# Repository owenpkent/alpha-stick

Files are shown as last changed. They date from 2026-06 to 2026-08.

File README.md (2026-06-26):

<div align="center">
  <h1>🎮 Alpha Stick</h1>
  <p><strong>Open-Source Adaptive Gaming Joystick</strong></p>
  <p>
    A 3D-printable, ESP32-powered joystick designed for gamers with limited mobility.<br/>
    Inspired by commercial solutions like QuadStick and Feather — but fully open and hackable.
  </p>
  <p>
    
    
    
    
    
    
  </p>
  <p>
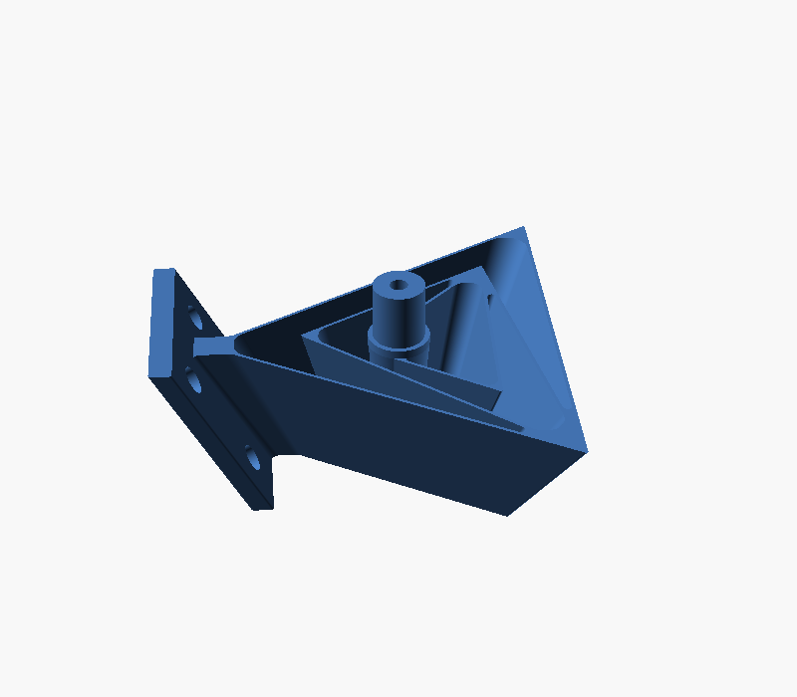
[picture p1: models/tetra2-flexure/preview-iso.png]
Tetra II spherical flexure joint — the primary pivot mechanism
    
  </p>
  <p><em>The pivot is a <strong>Tetra II spherical flexure</strong>: bearing-free, frictionless, and self-centering — the first gram of input already moves it.</em></p>
  <p>
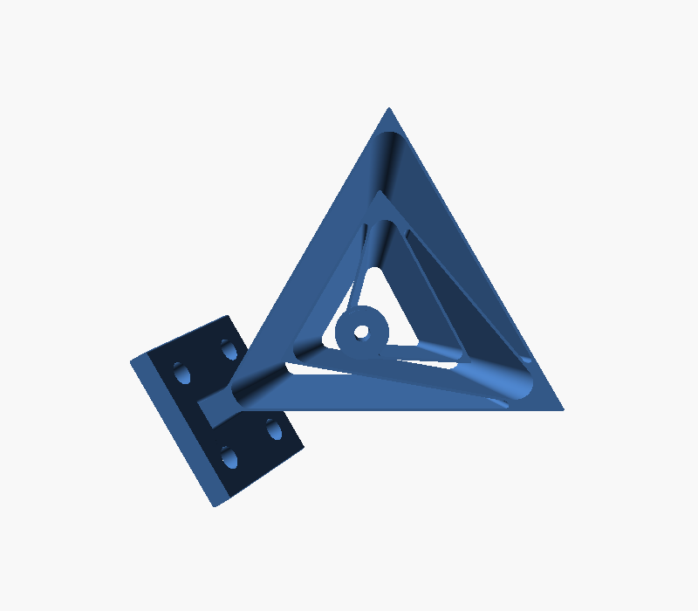
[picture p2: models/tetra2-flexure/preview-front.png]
Tetra II flexure — front view
    
    &nbsp;
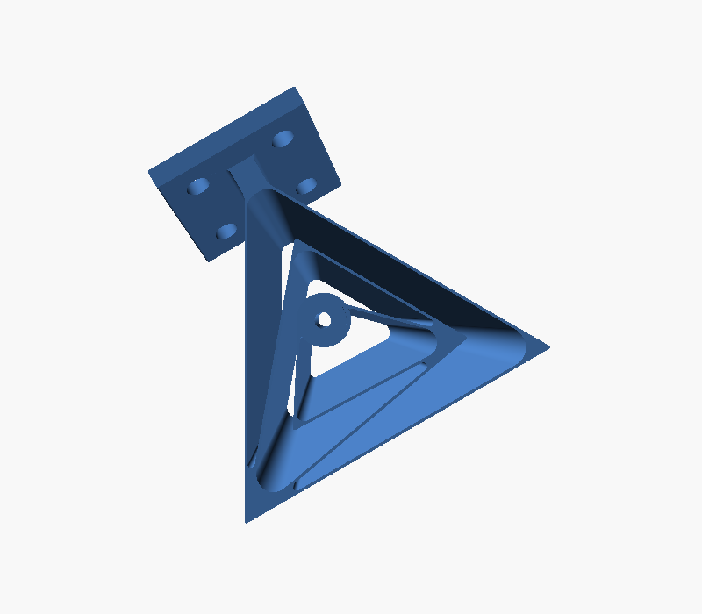
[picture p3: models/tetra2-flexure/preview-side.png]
Tetra II flexure — side view
    
  </p>
</div>

---

**New here?** Read the [Executive Summary](docs/EXECUTIVE_SUMMARY.md) (one page) or the [Whitepaper](docs/WHITEPAPER.md) (the full technical story). Want to help? See [CONTRIBUTING.md](CONTRIBUTING.md).

## Status

**Phase 0: Bench Validation** — V2 design baseline complete; proving the physics (force, noise, latency) before any product claims.

| Area | Status |
|---|---|
| Pivot mechanism | ✅ **Tetra II spherical flexure (primary)** — CAD in [`models/tetra2-flexure/`](models/tetra2-flexure/); ball-in-PTFE pod kept as the alternative |
| V2 First-Principles Design | 🔄 Baseline written: [docs/DESIGN_V2.md](docs/DESIGN_V2.md) |
| Hardware Design | ⏳ Planning (flexure pod + main board) |
| 3D Print Files | 🔄 Flexure STEP/STL in repo; pod bodies in progress |
| Firmware | ⏳ Planning |
| Documentation | 🔄 In Progress |
| Project Nimbus Integration | ⏳ Planned |

---

## Why Alpha Stick?

Commercial adaptive controllers are **expensive** ($200–$500+) and often **proprietary**. Gamers with disabilities deserve affordable, customizable options they can build, modify, and repair themselves.

**Alpha Stick aims to provide:**

- **Affordable** — 3D-printed enclosure + off-the-shelf electronics (~$30–50 BOM)
- **Open Source** — Hardware, firmware, and documentation all freely available
- **Customizable** — Modular design adaptable to different needs and abilities
- **Updateable** — OTA firmware updates via ESP32
- **Compatible** — Works with Xbox Adaptive Controller, PlayStation Access Controller, PC, and [Project Nimbus](https://github.com/owenpkent/Project-Nimbus)

---

## Inspiration

Alpha Stick draws from the best features of existing adaptive controllers:

| Product | Key Features We're Inspired By |
|---|---|
| **[QuadStick](https://www.quadstick.com/)** | Mouth-operated joystick, sip/puff input, multi-platform support |
| **[Feather](https://www.celticmagic.org/feather)** | Ultra-light force (<5g), magnetic sensing, tremor filter, adjustable sensitivity |
| **[Xbox Adaptive Controller](https://www.xbox.com/en-US/accessories/controllers/xbox-adaptive-controller)** | 3.5mm jack inputs, USB hub, profile switching, 3D-printable accessories |
| **[PlayStation Access](https://www.playstation.com/en-us/accessories/access-controller/)** | Swappable button caps, adjustable stick length, expandable inputs |
| **[Titan Two](https://www.consoletuner.com/products/titan-two/)** | Cross-platform compatibility, scripting, keyboard/mouse support |

---

## Planned Features

### Hardware
- **ESP32-S3** microcontroller with Bluetooth LE and USB HID
- **Tetra II spherical flexure pivot** — bearing-free, frictionless, self-centering; no springs, no break-away force
- **Contactless dual-Hall sensing** — a tilting magnet read by two TMAG5273 sensors; immune to temperature and creep
- **Ultra-low force** — under 5 grams full deflection, set by the flexure's blade geometry
- **3.5mm input jacks** — connect external switches and buttons
- **Modular enclosure** — 3D-printed, designed for different mounting options
- **Sip/puff interface** (optional) — pressure sensor input

### Firmware
- **USB HID gamepad** — plug-and-play on PC/consoles
- **Bluetooth LE gamepad** — wireless connection
- **XInput/DirectInput modes** — broad game compatibility
- **OTA updates** — update firmware over WiFi
- **Web-based configuration** — adjust sensitivity, deadzone, button mapping via browser
- **Profile system** — save and switch between configurations
- **Tremor filter** — configurable smoothing for users with tremors

### Software Integration
- **Project Nimbus integration** — use Alpha Stick with the virtual controller interface
- **Xbox Adaptive Controller companion** — connect via 3.5mm or USB
- **Configuration app** — desktop/mobile app for settings (future)

---

## Target Platforms

- **PC** — Windows (USB/Bluetooth), Linux, macOS
- **Xbox** — Via Xbox Adaptive Controller (3.5mm jack or USB)
- **PlayStation** — Via PS Access Controller or adapter
- **Nintendo Switch** — Via USB or Bluetooth (with appropriate mode)
- **Mobile** — Android/iOS via Bluetooth

---

## Project Structure

```
alpha-stick/
├── README.md                 # This file
├── LICENSE                   # MIT License
├── TODO.md                   # Task tracking
├── LLM_ONBOARDING.md         # AI assistant reference
├── docs/
│   ├── EXECUTIVE_SUMMARY.md  # One page: what and why
│   ├── WHITEPAPER.md         # The full technical narrative
│   ├── DESIGN_V2.md          # V2 design baseline (working doc)
│   ├── WORKFLOW.md           # Development loops & conventions
│   ├── HARDWARE.md           # Build reference & BOM
│   ├── FIRMWARE.md           # Firmware architecture (ESP-IDF)
│   ├── PHASE0_PARTS.md       # Bench parts list
│   ├── BENCH_LOG.md          # Measured results
│   ├── PRINTING.md           # 3D printing guide
│   ├── ASSEMBLY.md           # Assembly instructions
│   └── CONFIGURATION.md      # Configuration guide
├── hardware/
│   ├── schematics/           # KiCad or EasyEDA files
│   ├── pcb/                  # PCB design files
│   └── bom/                  # Bill of materials
├── firmware/
│   ├── main/                 # Entry point, mode supervisor
│   ├── components/           # Sensing, pipeline, HID, AS-Link, config
│   ├── web/                  # Web config UI source
│   └── sdkconfig.defaults    # ESP-IDF configuration
├── models/
│   ├── tetra2-flexure/       # Primary pivot: Tetra II flexure STEP + STL (CC-BY)
│   ├── stl/                  # Ready-to-print STL files (alternative pod)
│   ├── step/                 # STEP files for modification
│   └── source/               # FreeCAD/Fusion360 source files
├── software/
│   ├── web-config/           # Web-based configuration UI
│   └── tools/                # Utility scripts
└── examples/
    └── profiles/             # Example configuration profiles
```

---

## Hardware Overview

### Core Components

| Component | Purpose | Est. Cost |
|---|---|---|
| ESP32-S3 module | Main controller | $4–10 |
| Sensor pod (Tetra II flexure pivot + dual Hall + magnet) | Position input, <5 g force, self-centering | $5–7 |
| 3.5mm jacks (x4) | External switch inputs | $2 |
| Buttons (x2–4) | Direct button inputs | $1–2 |
| 3D-printed enclosure | Housing | $2–5 (filament) |
| USB-C connector | Power/data | $1 |
| Misc (wires, screws) | Assembly | $2–3 |
| **Total** | | **~$20–30** |

### Optional Add-ons

| Component | Purpose | Est. Cost |
|---|---|---|
| Hall-effect joystick | Ultra-smooth input | $10–20 |
| Pressure sensor | Sip/puff interface | $5–10 |
| LiPo battery + charger | Wireless operation | $10–15 |
| OLED display | Status/config display | $5 |

---

## Getting Started

> **Note:** Hardware and firmware are still in development. Check back soon!

### Prerequisites

- **3D Printer** — Any FDM printer (Ender 3, Prusa, etc.)
- **Soldering iron** — Basic through-hole soldering
- **ESP-IDF 5.x** — For firmware development ([install](https://docs.espressif.com/projects/esp-idf/en/stable/esp32s3/get-started/index.html))
- **ESP32-S3 board** — DevKitC or similar

### Quick Start (Coming Soon)

```powershell
# Clone the repository
git clone https://github.com/owenpkent/alpha-stick.git

# Navigate to firmware directory
cd alpha-stick/firmware

# Build and flash (ESP-IDF PowerShell)
idf.py set-target esp32s3; idf.py build flash

# Open web configuration
# Connect to "AlphaStick" WiFi network, navigate to http://192.168.4.1
```

---

## Project Nimbus Integration

Alpha Stick is designed to work seamlessly with [**Project Nimbus**](https://github.com/owenpkent/Project-Nimbus) — a virtual controller interface for accessibility.

### Integration Options

1. **Direct USB** — Alpha Stick appears as a standard gamepad; Project Nimbus can combine it with mouse input
2. **Bluetooth** — Wireless connection to PC running Project Nimbus
3. **Hybrid mode** — Use Alpha Stick for analog input, Project Nimbus for buttons and additional controls
4. **Configuration sync** — Share sensitivity curves and profiles between projects

### Use Cases

- **Alpha Stick + Project Nimbus** — Physical joystick for one hand, on-screen buttons for the other
- **Dual Alpha Sticks** — Two joysticks for flight sim or dual-stick shooters
- **Alpha Stick + Xbox Adaptive Controller** — Use Alpha Stick as an external joystick input

---

## Accessibility Features

Designed with input from the disability gaming community:

- **Ultra-light force** — under 5 g full deflection from the flexure; swap to a stiffer-blade flexure (or the adjustable ball-pivot pod) to retune
- **Configurable deadzone** — Accommodate tremors and limited precision
- **Tremor filtering** — Smooth out unintended movements
- **Button debouncing** — Adjustable for different switch types
- **One-handed operation** — Compact form factor, all controls accessible
- **Voice/switch control** — External switch inputs for additional buttons
- **Custom mounting** — Designed for RAM mounts, Magic Arms, and wheelchair trays

---

## Contributing

We welcome contributions from everyone! Areas where we especially need help:

- **3D modeling** — Enclosure designs for different needs
- **PCB design** — If you have KiCad/EasyEDA experience
- **Firmware development** — ESP32, ESP-IDF, Bluetooth HID
- **Testing** — Especially from users with disabilities
- **Documentation** — Tutorials, translations, videos

### How to Contribute

1. Fork the repository
2. Create a feature branch (`git checkout -b feature/my-feature`)
3. Make your changes with clear commit messages
4. Submit a pull request

See [CONTRIBUTING.md](CONTRIBUTING.md) for detailed guidelines.

---

## Roadmap

### Phase 1: Foundation (Current)
- [ ] Define hardware requirements
- [ ] Select core components
- [ ] Create initial 3D model
- [ ] Basic firmware scaffold

### Phase 2: Prototype
- [ ] Working breadboard prototype
- [ ] USB HID functionality
- [ ] Basic web configuration
- [ ] First printable enclosure

### Phase 3: Refinement
- [ ] Bluetooth support
- [ ] OTA updates
- [ ] Sip/puff option
- [ ] Community testing

### Phase 4: Release
- [ ] Documentation complete
- [ ] Multiple enclosure options
- [ ] Profile library
- [ ] v1.0 release

---

## Community

- **GitHub Issues** — Bug reports, feature requests, questions
- **Discussions** — Share your builds, ask for help
- **Discord** — (Coming soon)

---

## Related Projects

- **[Project Nimbus](https://github.com/owenpkent/Project-Nimbus)** — Virtual controller interface for accessibility
- **ATOS** — Modular ESP32-S3 wheelchair platform; Alpha Stick V2 is designed to act as its input node (see [docs/DESIGN_V2.md](docs/DESIGN_V2.md), section 9)
- **[Joypad OS](https://github.com/joypad-ai/joypad-os)** — Universal controller firmware for adapters and protocol translation (reference architecture)
- **[Xbox Adaptive Controller](https://www.xbox.com/en-US/accessories/controllers/xbox-adaptive-controller)** — Microsoft's adaptive gaming hub
- **[QuadStick](https://www.quadstick.com/)** — Commercial mouth-operated controller
- **[Feather Joystick](https://www.celticmagic.org/feather)** — Ultra-light force joystick
- **[OpenSwitchBoard](https://github.com/makersmakingchange/OpenSwitchBoard)** — Open-source switch interface
- **[Makers Making Change](https://makersmakingchange.com/)** — Community building assistive technology

---

## License

- **Code & firmware** — [MIT License](LICENSE).
- **Original hardware designs** (the pod, bench rig, bodies, toppers) — **CERN-OHL-P v2** (permissive), see [LICENSE-CERN-OHL-P-2.0.txt](LICENSE-CERN-OHL-P-2.0.txt).
- **Tetra II spherical flexure** (the primary pivot) — third-party design by Jelle Rommers under **Creative Commons Attribution (CC BY 3.0)**, used unmodified; credit is required if you share or build on it. See [models/tetra2-flexure/LICENSE](models/tetra2-flexure/LICENSE).

Bundled third-party components and their attribution are listed in [NOTICE.md](NOTICE.md).

---

## Acknowledgments

- The disability gaming community for feedback and inspiration
- [AbleGamers](https://ablegamers.org/) and [SpecialEffect](https://www.specialeffect.org.uk/) for advocacy
- Owen — project creator, wheelchair user with muscular dystrophy
- Everyone building accessible gaming solutions

---

<div align="center">
  <strong>Gaming is for everyone. Let's build it together.</strong>
</div>

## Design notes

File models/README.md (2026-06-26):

# Models

Printable parts for Alpha Stick V2. Print settings live in
[docs/PRINTING.md](../docs/PRINTING.md); the design rationale in
[docs/DESIGN_V2.md](../docs/DESIGN_V2.md).

## Tetra II flexure: the primary pivot mechanism

Alpha Stick V2 pivots on the **Tetra II spherical flexure joint** in
[`tetra2-flexure/`](tetra2-flexure/). It is a bearing-free compliant gimbal:
nested tetrahedron blade flexures give 3-DOF rotation about a remote centre that
floats ~50 mm out from the joint, with **no sliding surfaces** — so no friction,
no backlash, no break-away force, and the blades themselves provide the elastic
return to centre (no centering magnet, no spring, no threaded force adjuster).
The diametric sense magnet rides the moving platform and the dual TMAG5273 Hall
sensors read tilt exactly as before; only the pivot-and-return mechanism changes.

Tetra II flexure — isometric
Tetra II flexure — front
Tetra II flexure — side

| File | What it is |
|---|---|
| [`tetra2-flexure/Tetra2.STEP`](tetra2-flexure/Tetra2.STEP) | source CAD (B-rep); scale, thicken blades, or cut a stick mount in FreeCAD / Fusion / SolidWorks |
| [`tetra2-flexure/Tetra2.STL`](tetra2-flexure/Tetra2.STL) | ready-to-slice mesh of the same part |
| [`tetra2-flexure/README.md`](tetra2-flexure/README.md) | paper analysis, printing notes, and CC-BY attribution |

This is Jelle Rommers' design and carries an upstream **CC-BY** licence (credit
required), separate from the repo's MIT / CERN-OHL-P work — see the folder
README. Stiffness (= the force you feel) is hard to predict for the real
tetrahedron element and is set by blade geometry, material, and scale, so it is
a **Phase 0 bench measurement**, not a hand-calculated figure. A printed PLA
joint is fine for feel studies but creeps and fatigues under daily use; PETG or
a printed-then-cast/metal version are the follow-ups.

## Pod v0: the ball-pivot bench rig (alternative mechanism)

The pod parts below build the **alternative** ball-in-PTFE-cup mechanism with
magnetic centering — the original V2 path, kept as a fallback and as the bench
rig that characterises the dual-Hall sensing independent of the pivot choice
(see [docs/HARDWARE.md](../docs/HARDWARE.md#alternative-mechanism-ball-in-ptfe-pod)).

`source/pod-v0.scad` (OpenSCAD, fully parametric) generates the rig that
validates the V2 mechanism using the parts from
[docs/PHASE0_PARTS.md](../docs/PHASE0_PARTS.md). It is sized around the
**SparkFun Qwiic TMAG5273 breakout** (25.4 mm square), not the final 20 x 20 mm
pod PCB; v0 exists to produce the numbers the real pod gets sized from.

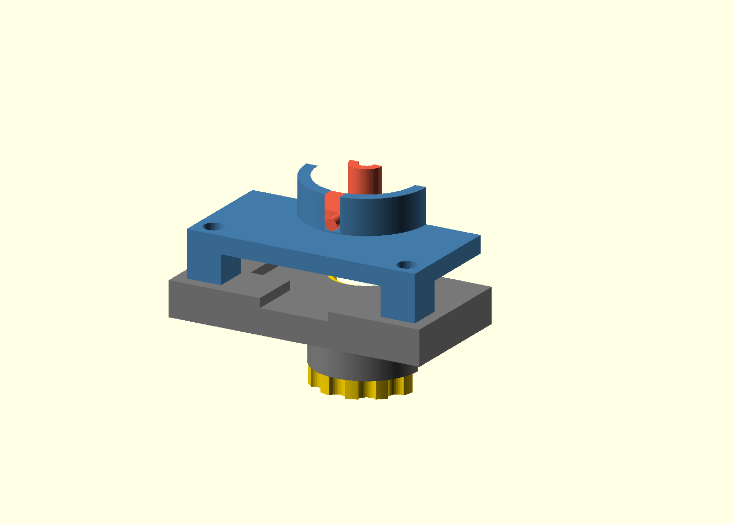
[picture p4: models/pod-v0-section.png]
Assembly cross-section


| Part | STL | What it does |
|---|-----|---|
| Stick hub | `stl/pod/stick-hub-v0.stl` | Printed dome pivot, D4x2 diametric magnet pocket (0.2 mm proud), anti-yaw pins, 2.6 mm carbon tube bore |
| Seat housing | `stl/pod/seat-housing-v0.stl` | PTFE-tape-lined spherical socket on a bridge over the breakout, anti-yaw slots, corner posts |
| Bench base | `stl/pod/bench-base-v0.stl` | Breakout pocket (PCB top lands flush), M12x0.75 threaded boss for the carrier, Qwiic cable reliefs |
| Adjuster carrier | `stl/pod/adjuster-carrier-v0.stl` | M12x0.75 thread, top pocket for a D10 ring magnet or M5 washer stack, grip wheel |
| Ball topper | `stl/toppers/topper-ball-v0.stl` | 8 mm ball, press-fits the carbon tube |
| Thread guide | `stl/pod/thread-guide-v0.stl` | String guide arm for the gram-scale force rig, notch near the 40 mm grip height |

### How the mechanism works in v0

The hub's printed dome (R6) rests in the housing socket lined with PTFE tape.
The sense magnet in the dome flat sits 1.5 mm above the TMAG5273 (the stack
arithmetic is derived, commented, and echoed in the .scad). The carrier rises
through the base from below; whatever sits in its pocket (ring magnet, washer
stack, or steel disc) attracts the sense magnet downward: that one attraction
is simultaneously the pivot preload and the centering force. Screwing the
carrier up or down sweeps the magnet-to-armature gap from about 4.4 to 9 mm,
which is the 1-8 gf force adjustment under test. Anti-yaw pins in collar slots
stop the hub from spinning (a diametric magnet reads yaw as direction change,
so this is required, not cosmetic). Tilt limit with default numbers: ~7 deg.

### v0 deviations from the production pod (docs/HARDWARE.md)

- Printed dome instead of a discrete steel ball; the bench compares feel and
  breakout force, and the steel-ball variant returns if PTFE-on-PETG loses.
- No steel washer on the hub; centering acts directly on the sense magnet.
- No carrier detents; printed-thread friction holds position at gram loads.
- ASSEMBLY.md describes the production pod build; for v0, assembly is: glue
  magnet in hub, tape the socket, drop hub in housing, screw housing to base
  over the breakout, thread the carrier in from below.

### Print notes

- Hub and housing at 0.12 mm; both export pre-flipped to their print
  orientation (hub neck-down so the dome prints as a smooth top surface;
  housing collar-down so the socket bowl faces up). No supports.
- The hub's anti-yaw pins print as short horizontal cantilevers; a little sag
  is fine (the slots have 0.6 mm total clearance).
- Base prints boss-down as exported, brim recommended.
- Thread binds? Adjust `thr_clr` (default 0.18) and reprint just the carrier.

### Regenerating

Edit parameters at the top of `source/pod-v0.scad`, then:

```powershell
& "C:\Program Files\OpenSCAD\openscad.com" -o models\stl\pod\stick-hub-v0.stl -D "part=`"hub`"" models\source\pod-v0.scad
```

Part selector values: `hub`, `housing`, `base`, `carrier`, `topper`, `guide`,
`plate` (all parts in print orientation), `section` (assembly cross-section).

## Layout

```
models/
+-- tetra2-flexure/  primary pivot: Tetra II flexure STEP + STL (third-party, CC-BY)
+-- source/          pod-v0.scad (parametric source of truth for the alternative pod)
+-- stl/             ready-to-print pod exports (regenerate after editing source)
+-- step/            reserved for the production pod (FreeCAD/Fusion era)
+-- community/       community-contributed toppers and bodies (created on first PR)
```

Third-party parts (currently the Tetra II flexure) keep their upstream licence
in their own folder README; everything else is the repo's MIT / CERN-OHL-P work.

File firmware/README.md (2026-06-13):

# Alpha Stick Firmware

ESP-IDF 5.x scaffold implementing the architecture in [docs/FIRMWARE.md](../docs/FIRMWARE.md).

> **Status: compiles clean in CI (ESP-IDF v5.3.2, esp32s3); not yet run on hardware.**
> The structure, task graph, pipeline math, and AS-Link wire format are real. The TMAG5273
> register values are written from datasheet memory and flagged with VERIFY comments;
> compiling proves nothing about them. The remaining Phase 0 firmware spikes
> ([TODO.md](../TODO.md)) are on-device: flash, enumerate, verify the simulation demo,
> then measure.

## Simulation mode

By default (`AS_SIMULATE_WHEN_NO_SENSOR=y`), if no TMAG5273 answers on I2C the sensing task
synthesizes a slow circle with a periodic Z-press. That means a **bare ESP32-S3 devkit with no
wiring at all** should enumerate as a gamepad+mouse+keyboard composite device and draw circles
in `joy.cpl`. This is the Phase 0 TinyUSB spike with zero soldering.

## Build

Use an ESP-IDF 5.x PowerShell (Espressif Windows installer):

```powershell
cd C:\Users\Owen\dev\alpha-stick\firmware; idf.py set-target esp32s3
idf.py build
idf.py -p COM5 flash monitor
```

DevKitC-1 has two USB connectors: flash/monitor via the **UART** connector; TinyUSB owns the
**USB (native)** connector. Plug both in during development.

Options live under `menuconfig -> Alpha Stick`:

| Option | Values | Notes |
|---|---|---|
| Build profile | GAMING / DRIVE | DRIVE tightens safety behavior (see docs/DESIGN_V2.md sec. 9); scaffold only logs the difference so far |
| Role | STICK / DONGLE | DONGLE (AS-Link to USB bridge) is a stub |
| Simulate when no sensor | y/n | The bare-devkit demo switch |

## Layout

| Path | Contents | State |
|---|---|---|
| `main/` | boot, task bring-up | working skeleton |
| `components/as_sensing/` | TMAG5273 driver, sensing task, seqlock mailbox, simulation | driver needs bench verify |
| `components/as_pipeline/` | profile types, radial deadzone, expo curve, 1-euro filter | implemented, host-testable math |
| `components/as_modes/` | 1 kHz router task, gamepad/mouse mapping, Z-click hysteresis | gamepad + mouse working paths |
| `components/as_hid_usb/` | TinyUSB composite descriptors (16-bit gamepad + mouse + keyboard + CDC), see [README](components/as_hid_usb/README.md) | documented; needs first enumeration test |
| `components/as_hid_ble/` | BLE HID | stub |
| `components/as_aslink/` | wire format header (vendorable into ATOS), CRC32, COBS | implemented, host-testable |
| `components/as_config/` | profile defaults, NVS persistence, USB CDC JSON config protocol (cJSON) | working; driven by [tools/](../tools/) |
| `components/as_web/` | WiFi AP + web UI | stub |

## Bring-up checklist

1. `idf.py build` (CI already proves this passes on ESP-IDF v5.3.2).
2. Flash a bare devkit, open Windows `joy.cpl`: gamepad circles from simulation mode.
3. Wire a TMAG5273 breakout (SDA 8, SCL 9, 3V3, GND), wave a magnet: log line flips from
   SIMULATION to LIVE and the axes follow the magnet.
4. Verify the TMAG5273 register writes against the datasheet (marked VERIFY in
   `tmag5273.cpp`) before trusting any noise numbers.

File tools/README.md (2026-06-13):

# Alpha Stick host tools

Two native, cross-platform tools that talk to an Alpha Stick V2 over USB:

- **`configurator.py`** (end user): a GUI to change axes, deadzone, response
  curve, tremor filter, mouse speed, button mappings, and macros.
- **`as_flash.py`** (developer): a CLI to flash firmware, erase, watch the
  serial console, and read or push profiles for scripting.

Both share `alphastick/`, a small library wrapping the USB CDC config protocol
and the profile model.

## Install

Requires Python 3.9+ (with `tkinter` for the GUI, which ships with the
python.org and most distro builds).

```powershell
python -m pip install -r tools/requirements.txt
```

## End-user configurator

```powershell
python tools/configurator.py
```

1. Pick the **Port** (the Alpha Stick is listed first) and **Connect**. The app
   reads the device's current profile.
2. Edit on the tabs. **Stick** and **Mouse** changes are pushed with
   **Apply (live)** and take effect immediately (no reboot).
3. **Save on device** persists across reboots. **Save file...** writes a `.json`
   profile you can share or back up; **Open file...** loads one.

Button mappings and macros are authored and saved now; the firmware applies them
once the input subsystem (jacks, sip/puff) and macro engine land. See
[scope note](#scope) below.

## Developer flasher

```powershell
# See available ports
python tools/as_flash.py ports

# Build the firmware first (ESP-IDF), then flash firmware/build
cd firmware; idf.py build; cd ..
python tools/as_flash.py flash --port COM7 --baud 921600

# Other actions
python tools/as_flash.py erase   --port COM7
python tools/as_flash.py monitor --port COM7
python tools/as_flash.py info
python tools/as_flash.py config get -o myprofile.json
python tools/as_flash.py config set -i myprofile.json --reboot
```

`flash` reads `firmware/build/flasher_args.json` (produced by `idf.py build`)
for the image offsets, so it always matches the partition layout. OTA is not
wired yet; it arrives with the `as_web` component.

## USB CDC config protocol

The device exposes a newline-delimited JSON command channel on its USB CDC
interface (firmware: `components/as_config/config_protocol.cpp`). Each request
is one JSON object; each response is one JSON line with an `ok` boolean.

| Command | Request | Response |
|---|---|---|
| info | `{"cmd":"info"}` | `{"ok":true,"device":...,"fw":...,"proto":"1","profile_name":...}` |
| get | `{"cmd":"get"}` | `{"ok":true,"profile":{...}}` |
| set | `{"cmd":"set","profile":{...}}` | `{"ok":true}` (merges named keys, applies live) |
| save | `{"cmd":"save"}` | `{"ok":true}` |
| defaults | `{"cmd":"defaults"}` | `{"ok":true,"profile":{...}}` |
| reboot | `{"cmd":"reboot"}` | `{"ok":true}` then the device restarts |

Errors return `{"ok":false,"error":"..."}`. The firmware ignores profile keys it
does not implement, so a host can always send a full profile (including
`buttons` and `macros`) and the device applies the subset it supports.

The profile JSON schema is documented in
[docs/CONFIGURATION.md](../docs/CONFIGURATION.md).

## Scope

The firmware implements the stick/mouse subset of the profile today (mode,
mount, deadzone, curve, filter, mouse). `buttons` and `macros` are part of the
host profile model and round-trip through files now; their runtime in firmware
is blocked on the jack/sip-puff input subsystem and is tracked in
[TODO.md](../TODO.md).

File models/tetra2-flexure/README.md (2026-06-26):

# Tetra II spherical flexure joint (original author files)

The author's original CAD for the **Tetra II** spherical flexure joint, used
directly. This is the real geometry, not a rebuild:

| File | What it is |
|---|---|
| `Tetra2.STEP` | source CAD (B-rep). Open and edit in FreeCAD / Fusion / SolidWorks |
| `Tetra2.STL` | ready-to-slice mesh of the same part |
| `preview-*.png` | renders of the actual part (front / iso / side) |

front iso side

This is the **primary pivot mechanism** for Alpha Stick V2: a compliant joint
has no bearings to bind, no friction, and no backlash, and the pivot floats out
in space where a hand naturally rotates. It is a third-party design and so
carries its own **CC-BY** licence (attribution below), separate from the repo's
MIT / CERN-OHL-P work; that licence travels with the part wherever it lives. The
ball-in-PTFE-cup pod is kept as the alternative mechanism (see
[docs/HARDWARE.md](../../docs/HARDWARE.md)).

> An earlier parametric OpenSCAD approximation lived here; it was a single
> tetrahedron element and did not capture the nested, variable-thickness real
> design, so it was dropped in favour of the author's STEP. It remains in git
> history (commit `8079109`) if ever wanted.

## What it is (from the paper)

Source: Rommers, van der Wijk, Herder, *"A new type of spherical flexure joint
based on tetrahedron elements"*, Precision Engineering 71 (2021) 130-140
([doi:10.1016/j.precisioneng.2021.03.002](https://doi.org/10.1016/j.precisioneng.2021.03.002),
CC-BY). It is open access; read it via the DOI above.

A spherical flexure joint is the compliant equivalent of a ball-and-socket: it
gives 3-DOF rotation about a single point **P** while constraining the three
translations. Unlike a ball joint it has no sliding surfaces, so no friction,
wear, or backlash, and it can be made in one printed piece.

Key facts that matter when reusing or editing this part:

- **Building block.** The joint is built from *tetrahedron elements*. Each
  tetrahedron element is three trapezoidal **blade flexures** (two in series,
  one in parallel) connected with no intermediate rigid bodies. The planes of
  all three blades pass through the rotation point **P**; that is what makes the
  motion purely rotational about P.
- **Tetra II specifically.** Three tetrahedron elements in a *nested* series
  configuration (Fig. 5). Two elements at an angle are enough for spherical
  motion; the third is added to raise stiffness. The three elements differ in
  both size and shape, which is why this is not cleanly parametric.
- **Remote centre.** P is a *remote* centre of rotation: it floats ~50 mm out
  from the joint face, not inside the body. Position your stick/lever so its
  natural pivot sits at P.
- **Variable blade thickness.** Real blades taper linearly from `t_max` to
  `t_min` along the element height so bending stress is spread evenly; the
  standard steel design uses `t_min = 0.5 mm`. The printed PLA version on
  Thingiverse uses ~0.7 mm walls.
- **Distributed compliance = large range of motion.** Strain is spread along
  curving blades rather than concentrated, so the joint deflects a long way
  before peak stress limits it.
- **Stiffness is the design lever, and it is hard to predict.** The paper's
  closed-form stiffness equations match FEA well for the *prism* simplification
  (NMAE 1.9%) but only qualitatively for the real *tetrahedron* element
  (NMAE 34.9%). Translation: do not trust a hand-calculated force figure for
  this part. Measure it on the bench, which is the Phase 0 approach anyway.

## For Alpha Stick

This is attractive for the ultra-low-force goal: a flexure stick has no
break-away friction, so the very first gram of input already moves it. Caveats
to validate on the bench:

- The paper's design targets steel (WEDM) or titanium (additive). **PLA** has a
  far lower modulus and poor fatigue life, so a printed version is fine for feel
  studies but will creep and fatigue under daily use. PETG or a printed-then-
  cast/metal version are follow-ups.
- The remote centre (~50 mm out) and the overall ~111 x 103 x 45 mm envelope are
  large for a handheld stick. Scaling the STEP down moves P and stiffens the
  blades non-linearly; re-measure force after any scale change.
- Single-piece print means a blade failure scraps the whole joint. Cheap to
  reprint, but worth noting for a daily-driver.

## Editing

Open `Tetra2.STEP` in FreeCAD (free), Fusion 360, or SolidWorks. The STEP is a
solid B-rep, so you can scale it, thicken blades, or cut a different stick mount,
then re-export an STL for slicing. There is no parametric feature tree in a STEP
export, so large changes are easier by re-deriving from the paper's parameters
than by editing the mesh.

Because this part is **CC BY**, any edited version you share must keep the
attribution below **and** state that you changed it (and what you changed).

## Printing notes (from the original author)

- Regular PLA is fine for a demonstrator; no flexible filament needed.
- Thin walls of ~0.7 mm work best on a 0.4 mm nozzle (two slightly overlapping
  perimeters).
- Rotation point sits ~50 mm from the joint surface.
- A second mesh on Thingiverse, `Tetra1_Requiring_supports`, is the version from
  the author's video; the Tetra2 here prints without supports.

## Attribution / licence

By **Jelle_Rommers**, Thingiverse
[thing:4841850](https://www.thingiverse.com/thing:4841850), licensed
**Creative Commons - Attribution (CC-BY)**. If you share or publish this part,
credit Jelle Rommers and link the original and the paper:

- Thingiverse: https://www.thingiverse.com/thing:4841850
- Paper: https://www.sciencedirect.com/science/article/pii/S0141635921000726
- Video: https://www.youtube.com/watch?v=DAngcygU7tc

This part carries an upstream CC-BY licence, separate from the repo's MIT /
CERN-OHL-P licensing for original work. It is also recorded repo-wide in
[NOTICE.md](../../NOTICE.md).

- **Modifications in this repo:** none — the files here are the author's original
  publication, used unmodified.
- **Licence version:** the Thingiverse listing labels it "Creative Commons -
  Attribution"; Thingiverse applies the **CC BY 3.0 Unported** generation for
  this option ([deed](https://creativecommons.org/licenses/by/3.0/)). Standalone
  text: [`LICENSE`](LICENSE) in this folder.

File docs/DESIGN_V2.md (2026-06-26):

# Alpha Stick V2: First-Principles Redesign

Status: **Design baseline, June 2026.** Supersedes the joystick-selection sections of
[HARDWARE.md](HARDWARE.md) and the load-cell approach in [ISOMETRIC_PARTS.md](ISOMETRIC_PARTS.md)
(both kept as reference). Firmware direction changes from Arduino/PlatformIO to ESP-IDF (section 8).

---

## 0. Thesis

Build one ultra-light input core (a contactless stick on a compliant flexure pivot requiring under
5 grams of force and about 2 mm of travel) and let firmware decide what it is: a USB/BLE gamepad,
a precision mouse, a keyboard, or a drive-input node for ATOS. The expensive part of every
adaptive controller is the input mechanism. Solve that once, at the physics level, and the rest
is software.

### Decisions at a glance

| Decision | Choice | Why | Alternative kept |
|---|---|---|---|
| Sensing | Dual TMAG5273 3D Hall, one tilting magnet | Contactless (zero added force), redundancy for drive use, ~$2 | MLX90393 if bench noise is too high |
| Return force | Elastic return built into the Tetra II flexure (no spring, no centering magnet) | The restoring force *is* the pivot; zero sliding friction, zero backlash | Active coils (Stage C); ball + magnet centering (alternative) |
| Pivot | Tetra II spherical flexure, printed one piece | No bearings, no sliding surfaces, no break-away friction; remote centre ~50 mm out | Ball in PTFE cup + magnet preload if printed-flexure creep/fatigue loses on the bench |
| Throw | +/-4 to 6 degrees (~+/-2-3 mm at fingertip) | Proprioceptive feedback without fatigue; well within the flexure's range | Stiffer-blade flexure or firmware near-isometric mode |
| Isometric load cells | **Dropped** | Sustained force is fatiguing; strain gauges drift; 4 cells + 2 ADCs + mux for worse UX | Docs archived |
| MCU | ESP32-S3 (MINI-1 module) | Native USB OTG + BLE + WiFi, same target as ATOS | ESP32-C3 cannot do USB HID composite well |
| Framework | ESP-IDF 5.x + TinyUSB + NimBLE | Composite HID, OTA rollback, ESP-NOW, shares toolchain with ATOS/espp | Arduino fine for quick sensor spikes |
| Mouse vs joystick | Both, always: composite HID device, runtime mode switch | No re-enumeration, one firmware | |
| ATOS link | "AS-Link" framed protocol (UART or ESP-NOW), mirrors ATOS drive-proposal semantics | ATOS host keeps final authority; stick is a sensor, never a motor controller | USB HID into Layer 2 Linux |

---

## 1. Requirements (with numbers)

### Hard requirements

| # | Requirement | Target | Notes |
|---|---|---|---|
| R1 | Full-deflection force | <5 gf, nominal ~3 gf target; set by flexure blade geometry/scale, **measured** on the bench (not per-session adjustable) | Measured at 40 mm reference grip point |
| R2 | Throw | +/-4 to 6 deg mechanical (+/-2.8 to 4.2 mm at 40 mm) | "Super low throw" |
| R3 | Breakout (force to first motion) | <0.5 gf (~0 with the flexure: no sliding surface to break away) | Friction budget, section 3 |
| R4 | Sensing | Contactless (Hall effect) | No pots, no strain gauges in the force path |
| R5 | MCU | ESP32-S3 | USB HID + BLE HID + WiFi config/OTA |
| R6 | Modes | Gamepad, mouse, keyboard, ATOS input | Runtime switchable |
| R7 | Wired latency, stick to USB report | <5 ms | Section 8 budget |
| R8 | Effective resolution | >=8 bits per axis at 1 kHz, >=9 after filtering | Comparable to commercial thumbsticks |
| R9 | Core BOM | <$35 wired, <$50 with battery | Project goal |
| R10 | Buildable | FDM printer + soldering iron, no machining | Project goal |

### Soft requirements

- Z-axis press-to-click at <5 gf (same Hall sensor, no switch in the force path)
- 4x 3.5mm switch jacks (XAC-style ecosystem)
- Sip/puff option
- Battery option, 10+ hours BLE
- Sensor pod usable in multiple bodies: desktop base, chin boom, mouth-stick frame, thumb pad

---

## 2. Why neither v1 option survives first principles

**Option A, gimbal potentiometer sticks (KY-023, PSP, even Hall RKJXV):** centering springs on
these parts sit at 150-450 gf full deflection, two orders of magnitude above target. Swapping
springs does not fix it: the gimbal has sliding friction at four contact lines, and at the 3 gf
scale that friction becomes the dominant feel (stiction notches, hysteresis, no clean return to
center). The architecture is wrong for the force target, not just the spring.

**Option B, isometric load cells (v1's accessibility path):** zero motion sounds ideal, but:

1. **Sustained force is the fatigue mode.** Holding a direction means holding a force forever.
   For muscular dystrophy and similar conditions, a tiny displacement that can be *rested at*
   beats a force that must be *maintained*.
2. **No proprioception.** Nothing moves, so the only feedback is on-screen. Tremor and overshoot
   get worse without position feedback.
3. **Strain gauges drift** with temperature and creep, so center wanders and needs re-taring,
   which is exactly what you cannot tolerate while driving a cursor or a wheelchair.
4. **Complexity:** 4 cells + 2 precision ADCs + an I2C mux to do badly what one $1 Hall sensor
   does well.

**The synthesis:** a *small-displacement* stick (2-3 mm) at *near-zero force* (3 gf) gives the
minimal range-of-motion benefit that motivated the isometric design, plus real proprioceptive
feedback, plus rest-at-position, with one contactless sensor. Users who want a stiffer, almost
isometric feel fit a stiffer-blade flexure; the throw is small enough that ~8 gf feels nearly rigid.

---

## 3. The force budget (where every gram goes)

Force at the 40 mm grip point, full deflection:

| Source | Budget | How |
|---|---|---|
| Flexure restoring force (the intended force) | nominal ~3.0 gf, fixed by the part | The flexure blades bend elastically; force is set by blade geometry/material/scale and measured on the bench (section 5) |
| Pivot friction | ~0 gf | The flexure has no sliding surfaces, so no break-away friction and no stiction |
| Seal/boot | 0 (default) | Labyrinth gap, no contacting seal. Optional silicone boot costs 0.5-1 gf, off by default |
| Sensor | 0 | Contactless |
| Gravity bias (tilted mounts) | up to ~1.3 gf equivalent | See below; handled by mass budget + firmware tare |

**Gravity is a real term at this scale.** A stick with moving mass m and center of gravity h
above the pivot, mounted horizontally (chin boom, vertical surface), sees a constant gravity
torque of m * g * h. With m = 2.5 g and h = 20 mm that is 50 gf-mm, i.e. ~1.25 gf at the 40 mm
grip point, nearly half the nominal centering force. Therefore:

- **Moving-mass budget: <2.5 g total** (stick tube + topper + magnet + ball). Carbon tube,
  hollow printed toppers, one small magnet.
- Firmware applies a **mount-orientation tare** (stored per profile) so the gravity bias reads
  as zero offset.
- Tilted mounts (chin boom, vertical surface) use a stiffer-blade flexure so the stick still
  returns to center against gravity. The flexure's moving platform adds to the moving mass, so
  re-derive this budget against the measured part rather than the ball-pivot table above.

This is also why the topper system is magnetic quick-swap with a <1 g mass budget per topper.

---

## 4. Sensing: one tilting magnet, two 3D Hall sensors

### Geometry

```
                topper (magnetic quick-swap, <1 g)
                  |
                  |   stick: carbon tube, 25/40/60 mm options
                  |
              [ P ]            remote rotation centre, ~50 mm out
                  :
        ##########:##########   Tetra II spherical flexure (printed one piece):
        ##  nested blade   ##   3-DOF rotation about P, no sliding surfaces,
        #####moving########      elastic return to centre built in
             [N52 D4x2]          diametric disc magnet on the moving platform,
                  |              tilts 1:1 with stick angle
         . . . . gap ~1.5 mm . . . .
       =============================    sensor pod PCB (~20 x 20 mm)
        [TMAG5273 A]   [TMAG5273 B]     dual 3D Hall, I2C, ~3 mm apart
       =============================    flexure base mounts here
```

### Why field *direction*, not magnitude

The magnet tilts with the stick, so the field vector at the sensor rotates 1:1 with stick angle.
Computing tilt from the field direction (after a one-time calibration map) and normalizing by
|B| makes the measurement first-order immune to:

- NdFeB temperature coefficient (~ -0.12 %/degC of magnitude, direction unaffected)
- Axial gap creep in printed parts (magnitude changes, direction does not)
- Magnet strength tolerance between builds

The only ferromagnetic part is the sense magnet itself (the flexure is all-polymer), so there is
little to distort the field, and the calibration map absorbs whatever static asymmetry the build has.

### The Z axis (press-to-click)

A spherical flexure constrains the three translations, so axial press is *stiff* — unlike the ball
pod, pressing does not freely close the magnet-sensor gap. Z press-to-click is therefore a
follow-up on the flexure: either a deliberately compliant axial element under the pod (a soft
mount that lets |B| dip a little under press, read with hysteresis + debounce, no switch in the
force path) or a jack/topper switch. The ball-pivot alternative keeps the free gap-change Z-click.

### Dual sensors: cheap redundancy

Two TMAG5273 (two of the four factory I2C address variants) read the same magnet:

- **Gaming build:** average them (small noise win) or run one and keep the second dark.
- **Drive build (ATOS):** continuous plausibility cross-check. Disagreement >3% of full scale
  for >50 ms latches a fault and zeroes output (section 9). This is the cheapest path to a
  drive-grade input: ~$1 of silicon, no exotic parts.

### Expected performance (validate on bench, Phase 0)

| Parameter | Estimate | Basis |
|---|---|---|
| Field swing per axis | ~ +/-3.5-8 mT | |B| 40-100 mT, +/-5 deg rotation |
| Sensor noise after 8x averaging | tens of uT rms | TMAG5273 datasheet class |
| Effective resolution at 1 kHz | 8-9 bits/axis | swing / noise; dual-sensor and pipeline filtering add margin |
| Sample rate | 1 kHz output (sensor ~3 kSPS raw) | 25 us/channel conversions |

8-9 effective bits matches or beats typical commercial thumbsticks. If bench results disappoint,
the drop-in upgrade is MLX90393 (16-bit, configurable oversampling) on the same pod footprint.
HID reports are 16-bit with dithered scaling either way.

### Calibration

1. **Factory/build cal:** guided sweep in the web UI (center, 8 compass points, full circle)
   fits a small polynomial map from field vector to (theta_x, theta_y, z). Stored in NVS.
2. **Center tare:** on demand (button/web UI) and automatically at boot *only if* the stick has
   been continuously still and within 2% of stored center for 3 s. Never silently re-tares while
   in use: silent re-centering is how drift bugs eat trust, and in drive mode it is dangerous
   (drive build disables auto-tare entirely).

---

## 5. Mechanics

### Pivot trade study

| Option | Friction | Wear | Printable | Verdict |
|---|---|---|---|---|
| 2-axis gimbal | 4 sliding contacts | yes | hard | No: friction dominates at 3 gf |
| **Tetra II spherical flexure** | zero (no sliding) | creep/fatigue (polymer) | yes, one piece | **Chosen.** No break-away friction, no backlash, self-centering; creep/fatigue is the accepted risk, bounded by material (PETG/metal) and the ball-pivot fallback |
| Ball in PTFE cup + magnetic preload | ~0.1-0.2 gf equiv | low (PTFE) | yes | Alternative / fallback; also characterises the sensing on the bench independent of the pivot |
| Jewel/pivot bearing | near zero | low | no ($) | Fallback if both printed paths disappoint |

The flexure was the rejected option in the V1-era version of this study — printed-polymer creep
moving centre over weeks is a real failure mode. It is promoted to primary now because its
bench-validatable upside (literally zero break-away friction, the first gram of input already
moves it, plus self-centering with no extra parts) is exactly the ultra-low-force thesis, and the
creep/fatigue risk is bounded: PETG over PLA, a printed-then-cast/metal path, and the ball-pivot
pod kept as a drop-in fallback if the bench says creep wins.

### Centering and force: the flexure does both

The Tetra II flexure's blades bend elastically, so the joint *is* the return-to-centre spring —
no centering magnet, no ferrous washer, no threaded carrier. Required restoring torque is tiny
(3 gf at 40 mm = 120 gf-mm = ~1.2 mN-m), and the flexure delivers it with zero sliding friction
and zero backlash.

Force is therefore a property of the printed part, not a user dial. It is set by blade thickness,
the nested-element geometry, material modulus, and overall scale — and the paper's closed-form
stiffness matches the real tetrahedron element only qualitatively (NMAE ~35%), so **measure it on
the bench** (Phase 0) rather than trusting a calculation. To retune feel, print a flexure with
different blade thickness or a scaled STEP (scaling moves P and stiffens the blades non-linearly —
re-measure). Per-session, tool-free force adjustment is the one thing given up versus the
magnetic-carrier design: it returns as the Stage C active-coil feature below, and the ball-pivot
alternative keeps the threaded adjuster for builds that need it.

### On magnetic levitation (asked and answered)

Earnshaw's theorem rules out stable levitation with static permanent magnets alone; every
"floating" stick needs either a mechanical constraint or active control. So:

- **Now (Stage A):** *constrained passive compliance*: the flexure carries both the constraint
  and the restoring force, with no sliding surfaces and no centering magnet. Zero break-away
  friction, zero backlash; the wear mode is polymer creep/fatigue, bounded by material choice.
  This captures ~90% of what maglev promises at ~0% of the complexity.
- **Later (Stage C, "Field"):** *active magnetics*: four planar coils in the sensor-pod PCB
  layers push on the stick magnet, closed-loop at 1 kHz from the Hall sensors. That unlocks
  firmware-programmable centering force (0 to ~10 gf), virtual detents and walls, haptic ticks,
  and **active tremor damping** (velocity-proportional opposing force at the physical layer, not
  just filtering). Torque needed is ~1.2 mN-m, which is plausible for PCB coils at this gap but
  must be proven; Stage C begins with a single go/no-go bench test of coil force. Power budget
  ~100-300 mW when active, so it is a wired/dock feature first.

No commercial adaptive joystick offers a programmable force field. Stage C is the "next level"
bet; Stages A and B do not depend on it.

### The sensor pod: one core, many bodies

Everything input-critical lives in a self-contained **pod**: flexure pivot + magnet + dual Hall
on a ~20 x 20 mm satellite PCB, connected to the main board by a 6-pin JST-SH/FFC
(3V3, GND, SDA, SCL, INT_A, INT_B). The pod mounts in:

- **Desktop base** (default): main PCB, jacks, USB-C, battery
- **Chin boom pod**: pod + cable only, electronics stay on the chair rail
- **Mouth-stick frame**: pod behind a food-safe mouthpiece adapter (QuadStick-style use)
- **Thumb pad**: pod in a 30 mm puck for tray mounting

One calibration procedure, one firmware, four form factors.

### Toppers and mounting

- Toppers: magnetic quick-swap, <1 g each: 8 mm ball, 14 mm dish, lip bar, T-bar,
  20/40 mm extensions, mouthpiece adapter
- Base: AMPS hole pattern + 1/4-20 brass insert (RAM mounts, Magic Arms, wheelchair trays)
- Printed in PLA/PETG; the flexure prints as one piece (PETG preferred over PLA for creep and
  fatigue life). The ball-pivot alternative uses a PTFE cup (machined insert or printed PCTG +
  PTFE tape)

---

## 6. Electronics

### Block diagram

```
                       +--------------------------------------+
   sensor pod          |              main board              |
  +-------------+      |                                      |
  | TMAG5273 x2 |--I2C-|  ESP32-S3-MINI-1                     |
  | magnet+flex |      |   |- USB OTG --- USB-C ---> PC/XAC   |
  +-------------+      |   |- BLE HID ------------> wireless  |
                       |   |- ESP-NOW ----> dongle / ATOS S3  |
  4x 3.5mm jacks ------|   |- UART (AS-Link) -----> ATOS S3   |
  2x tactile ----------|   |- WiFi AP ---> web config + OTA   |
  sip/puff (opt) --I2C-|                                      |
                       |  BQ24074 charger + MAX17048 gauge    |
                       |  (battery option)   WS2812  DRV2605L |
                       +--------------------------------------+
```

### Parts

| Block | Part | Why |
|---|---|---|
| MCU | ESP32-S3-MINI-1-N8 | Native USB OTG (TinyUSB), BLE 5, WiFi, same target/toolchain as ATOS |
| Hall sensors | 2x TMAG5273A1 (different address variants) | 3-axis, I2C, ~$0.80 each |
| Charger | BQ24074 | Power-path: runs while charging, no TP4056 brownout dance |
| Fuel gauge | MAX17048 | Real % instead of voltage guessing |
| Battery | LiPo 503035 500 mAh (optional) | 10-20 h BLE estimate, validate |
| Regulator | RT9080-33 class LDO | Low IQ |
| USB | USB-C 16-pin, CC resistors, USBLC6-2SC6 ESD | Proper device behavior |
| Jacks | 4x PJ-320A 3.5 mm mono + RC debounce + ESD | XAC-style switch ecosystem |
| Sip/puff (opt) | MPXV7002DP (analog, matches v1 docs) or Honeywell ABP I2C | +/-2 kPa differential fits sip/puff pressures |
| Haptics (opt) | LRA + DRV2605L | Mode-change/click confirmation ticks |
| Status | 2x WS2812B-2020 | Mode, battery, pairing |
| Expansion | 1x Qwiic/STEMMA-QT | Future sensors without respins |

Keep the WS2812 and any speaker magnets >15 mm from the sensor pod; static fields calibrate out,
but switching currents near the Hall sensors do not.

### Pin map (main board, draft)

| Function | GPIO | Notes |
|---|---|---|
| I2C0 SDA/SCL (pod + gauge + opt sensors) | 8 / 9 | 400 kHz-1 MHz |
| Pod INT_A / INT_B | 10 / 11 | Conversion-ready |
| Jacks 1-4 | 4 / 5 / 6 / 7 | Pullups, RC, ESD |
| Buttons 1-2 | 12 / 13 | |
| WS2812 | 48 | |
| Haptic EN | 14 | DRV2605L on I2C0 |
| Sip/puff ADC | 1 | ADC1_CH0 (analog option) |
| UART AS-Link TX/RX | 17 / 18 | To ATOS host |
| USB D-/D+ | 19 / 20 | Fixed |

(Avoids strapping pins 0/3/45/46. Final assignment at schematic time.)

### Core BOM estimate (wired build)

| Item | Cost |
|---|---|
| ESP32-S3-MINI-1-N8 | $3.50 |
| 2x TMAG5273 | $1.60 |
| Magnets (sense + toppers; no ring) | $2.00 |
| USB-C + ESD + regulator + passives | $2.50 |
| 4x 3.5 mm jacks | $1.60 |
| Buttons, LEDs, misc | $1.50 |
| PCBs (main + pod, JLC) | $4.00 |
| Brass/nylon fasteners (flexure is printed) | $0.50 |
| Printed parts (incl. Tetra II flexure) | $3.50 |
| **Core total** | **~$20** |
| Battery option (LiPo + BQ24074 + MAX17048) | +$13 |
| Sip/puff option | +$10 |
| Haptic option | +$4 |
| ESP-NOW dongle (minimal second S3 board) | +$9 |

Within R9 with margin.

---

## 7. What it acts as: modes

All USB modes live in **one composite HID device** (gamepad + mouse + keyboard report IDs, plus
CDC for config). Mode switching changes which reports stream; the device never re-enumerates.
BLE exposes the same report IDs in one HID service.

| Mode | Behavior |
|---|---|
| **Gamepad** | X/Y -> left stick (16-bit), Z-press + jacks + buttons -> buttons; second-stick and trigger mappings per profile |
| **Mouse** | Deflection -> pointer velocity through its own curve; Z-press = left click; jacks = right/middle/back; **dwell click** (configurable radius + time) for users who cannot click; scroll mode toggle; precision (half-speed) toggle |
| **Keyboard** | 8-way WASD/arrows with hysteresis, for menu UIs and games without stick support |
| **ATOS input** | AS-Link frames out UART/ESP-NOW, HID silent (section 9) |
| **Dual** | Gamepad + mouse simultaneously (e.g. stick aims, dwell clicks) |

### Platform reach (honest version)

| Platform | Path | Confidence |
|---|---|---|
| PC (Win/Linux/macOS) | USB composite HID / BLE HID | High |
| Xbox | **Via XAC USB port** as generic HID stick (X1/X2) | Medium-high; verify against XAC's supported-device behavior in Phase 0 |
| PlayStation | Via PS Access **3.5 mm AUX ports** for switch-type signals; analog passthrough not assumed | Medium |
| Switch | BLE Pro-Controller emulation (community-proven approach) | Medium |
| Android/iOS | BLE HID gamepad/mouse | High |
| Project Nimbus | Appears as standard HID; Nimbus layers on-screen controls; share curve/profile JSON schema | High |

Native XInput/console-auth modes are explicitly out of scope (auth chips); the XAC and Access
controllers are the sanctioned adaptive paths and we design to them.

---

## 8. Firmware (ESP-IDF)

### Why ESP-IDF now

TinyUSB composite control, NimBLE multi-report HID, ESP-NOW, and OTA-with-rollback are all
first-class in IDF and awkward in Arduino-on-S3. ATOS is ESP-IDF + espp on the same chip, so
components (logging, task wrappers, filters) and toolchain knowledge transfer directly.
Arduino remains fine for throwaway sensor bring-up spikes.

### Task graph

```
 sensor_task (core 1, 1 kHz, highest prio)
   read both TMAG5273 -> cross-check -> calibration map -> pipeline -> mailbox
 router_task (core 0)
   mailbox -> active mode mapping -> usb_hid / ble_hid / aslink writers
 ui_task        LEDs, haptics, button combos, force-adjuster hints
 config_task    WiFi AP + web UI + WebSerial (config mode only)
 watchdog       feeds only if sensor_task meets deadline and data is fresh
```

Latest-value seqlock mailbox between producer and writers (same pattern as ATOS's clamped
setpoint mailbox): writers never block the 1 kHz loop.

### Processing pipeline (order matters)

1. Calibration map (field vector -> theta_x, theta_y, z)
2. Mount-orientation tare (gravity bias)
3. Axis rotation (mounting angle) + invert flags
4. **Radial** deadzone (preserves diagonals, unlike per-axis)
5. Response curve LUT (linear/expo/log/S, per profile, separate curves for gamepad vs mouse)
6. **1-euro filter** for tremor (low lag at speed, heavy smoothing near rest; strictly better
   than the v1 fixed EMA), plus optional 3-12 Hz biquad notch for intention tremor
7. Slew limiter (optional, drive mode default-on)
8. 16-bit quantize with dither

### Latency budget (R7)

| Stage | Budget |
|---|---|
| Sensor conversion + averaging | ~0.6 ms |
| Pipeline | <0.1 ms |
| USB FS HID poll | 1 ms |
| **Wired total** | **~2-3 ms** |
| BLE (7.5 ms conn interval) | ~9-15 ms |
| ESP-NOW -> dongle -> USB | ~3-5 ms |

### Config and updates

- Profiles: JSON in NVS/LittleFS; curve/deadzone/filter/mapping/mount-tare per profile;
  hold-combo or jack to switch; shared schema with Project Nimbus
- Web UI over WiFi AP (live stick visualization, guided calibration, curve editor) plus
  WebSerial/WebHID over the CDC interface for no-WiFi config
- OTA: esp_https_ota with A/B partitions and automatic rollback; web upload kept as fallback

---

## 9. ATOS integration (the next level)

ATOS's Layer 1 whitepaper designs input-device integration but has not built it, and its host
owns the joystick and the final motor write. Alpha Stick v2 slots into exactly that hole: it is
a **high-integrity input sensor node**, never a motor controller.

### Link options

| Link | Use |
|---|---|
| UART, COBS-framed, 1 Mbaud | Wired on-chair, deterministic, preferred for drive |
| ESP-NOW direct to the ATOS S3 | Wireless on-chair, ~2-4 ms, no pairing UX |
| USB HID into Layer 2 (Linux) | Pointer/UI control of the chair's compute layer, never drive |

### AS-Link frame (v1 draft)

Semantics deliberately mirror `atos_drive_proposal_t` (normalized axes, TTL, monotonic seq) so
the ATOS-side gateway is a thin map:

```c
struct aslink_input_v1 {        // little-endian, COBS-framed, 20 bytes
    uint8_t  ver;               // 0x01
    uint8_t  type;              // 0x01 input, 0x02 health
    uint16_t seq;               // monotonic, host drops dupes/regressions
    int16_t  x_q15, y_q15;      // normalized [-1, +1] in Q15, post-pipeline
    int16_t  z_q15;             // press axis
    uint16_t buttons;           // jacks, sip/puff thresholds, Z-click
    uint16_t ttl_ms;            // host decays output to zero when stale
    uint8_t  flags;             // CAL_VALID | DUAL_SENSOR_OK | TEMP_OK | TARE_STABLE
    uint8_t  reserved;
    uint32_t crc32;
};                              // + 1 Hz health frame: fw version, sensor
                                //   disagreement stats, temperature, uptime
```

ATOS side: an `alpha-stick-gateway` module at `ATOS_LEVEL_L3_COMMAND` with
`ATOS_CAP_PROPOSE_DRIVE | ATOS_CAP_READ_TELEMETRY | ATOS_CAP_LOGGING`, mapping x/y to
linear/angular with ATOS-side curves and submitting proposals the host clamps as usual. The ABI
needs one addition (host owns the UART): a `read_input_frame()` host service behind a new
`ATOS_CAP_READ_INPUT_STREAM` capability, consistent with the whitepaper's input-router design.

### Drive build vs gaming build

Driving a wheelchair is a different integrity domain than gaming. Same hardware, **separate
firmware build profile**, honest about the differences:

| Property | Gaming build | Drive build |
|---|---|---|
| Dual-sensor cross-check | optional averaging | **mandatory**; >3% FS disagreement >50 ms latches fault, output zero, recover only at neutral + explicit ack |
| Auto-tare | idle-conditional | **disabled**; manual tare only while ATOS reports drive_disabled |
| Stale behavior | last value briefly held | TTL decay to zero (host side, AS-Link contract) |
| Boot behavior | live immediately | output held zero until stick observed neutral 500 ms |
| Tremor filter | user preference | slew limiter default-on; ATOS host applies its own envelope regardless |
| Watchdog | task WDT | task WDT + health frame; missing health = host treats input as dead |
| Radio | BLE/WiFi as configured | WiFi off; BLE off in wired mode |

Design posture aligns with ISO 7176-14 (power wheelchair control systems) but **no compliance is
claimed**: Alpha Stick proposes, the ATOS host's limit governor and safe-state policy dispose.
E-stop remains an ATOS-side physical input; AS-Link carries no stop authority, only intent.

---

## 10. Staged roadmap

### Stage A: "Glide" (the core product)

Passive pod (Tetra II flexure pivot + dual Hall sensing), desktop base, USB composite
gamepad/mouse/keyboard, BLE HID, web config, profiles, OTA.

**Exit criteria (bench-measured, not vibes):**
- Flexure full-deflection force measured at 40 mm (pull gauge); a printed flexure landing near the ~3 gf nominal target, with a stiffer-blade variant on hand for tilted mounts
- Breakout <0.5 gf (expected ~0); release returns within 0.5% FS of center
- Stationary noise <0.5% FS p-p after pipeline; >=8 effective bits demonstrated
- Wired stimulus-to-report latency <5 ms (logic analyzer)
- Center drift <1% FS over 2 h, 15-35 degC
- 100k-cycle deflection + soak rig: bound flexure creep/fatigue — force and centre drift stay within spec, or change material/scale (PETG/metal) until they do
- Owen daily-drives it for gaming and desktop mousing (the real test)

### Stage B: "Bridge" (the ecosystem release)

3.5 mm jacks, sip/puff, chin/mouth/thumb pod bodies, ESP-NOW dongle, AS-Link over UART +
ATOS gateway module prototype, XAC/PS-Access/Switch verification, Nimbus profile schema,
battery option, kit documentation.

### Stage C: "Field" (the research bet)

PCB-coil active stage: go/no-go force bench first (can four planar coils produce ~1.2 mN-m at
the working gap?), then programmable centering, virtual detents, haptic ticks, active tremor
damping. Wired/docked feature first; falls back cleanly to Stage A passive behavior.

---

## 11. Risks and open questions

| Risk | Mitigation |
|---|---|
| Hall SNR below 8 effective bits at +/-5 deg | First Phase 0 bench item; MLX90393 fallback footprint on pod v0 |
| Printed-flexure creep/fatigue moves centre or changes force over weeks | The accepted primary risk: 100k-cycle + soak bench tests; PETG over PLA, then printed-then-cast/metal; ball-pivot pod is the drop-in fallback |
| Flexure force not predictable from the paper (NMAE ~35%) and not per-session adjustable | Measure on the bench, iterate blade thickness/scale; per-session tuning deferred to Stage C coils; ball-pivot adjuster as alternative |
| Flexure remote centre (~50 mm) and envelope (~111 x 103 x 45 mm) are large for a handheld stick | Scale the STEP down (re-measure force; scaling moves P non-linearly); mount the stick so its natural pivot sits at P |
| S3 BLE power too high for 10 h on 500 mAh | Measure; modem sleep tuning; bigger cell fits the bay |
| XAC rejects generic HID stick | Test early (Phase 0); fallback is XAC 3.5 mm for buttons + USB on PC only |
| ATOS ABI lacks input-stream service | Filed as proposed `ATOS_CAP_READ_INPUT_STREAM`; gateway can prototype against a host stub |
| Moving mass creeps over 2.5 g with toppers | Mass column in topper README; chin/vertical profiles default stiffer |

---

## 12. Relationship to existing docs

- [HARDWARE.md](HARDWARE.md): rewritten to this baseline; it is the build reference (parts,
  pins, wiring, BOM), while this document holds the rationale.
- [FIRMWARE.md](FIRMWARE.md): rewritten to this baseline (ESP-IDF, task graph, HID, AS-Link).
- [ISOMETRIC_PARTS.md](ISOMETRIC_PARTS.md): archived as an alternative path; the rationale for
  dropping it is section 2.
- ATOS references: `docs/whitepaper-atos-layer1-modules.md` and `docs/display-casting.md` in the
  ATOS repo, plus `atos_module_abi.h` for the descriptor/capability/proposal contract.

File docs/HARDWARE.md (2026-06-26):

# Hardware Documentation

Build reference for Alpha Stick **V2**. Rationale, trade studies, and the force/latency budgets
live in [DESIGN_V2.md](DESIGN_V2.md); this file is what you build. The V1 load-cell isometric
approach is archived in [ISOMETRIC_PARTS.md](ISOMETRIC_PARTS.md).

---

## Overview

Two boards, one cable:

- **Sensor pod (~20 x 20 mm PCB + flexure joint):** the entire input mechanism. The stick
  pivots on a **Tetra II spherical flexure** (compliant, bearing-free, self-centering — no
  pivot ball, no centering magnet, no force adjuster); a tilting diametric magnet on the
  flexure's moving platform is read by dual 3D Hall sensors.
- **Main board:** ESP32-S3, USB-C, 4x 3.5 mm switch jacks, options (battery, sip/puff,
  haptics), connected to the pod by a 6-pin cable.

The split matters: the pod drops into different bodies (desktop base, chin boom, mouth-stick
frame, thumb puck) without electronics changes.

The **ball-in-PTFE-cup pod with magnetic centering** is retained as the
[alternative mechanism](#alternative-mechanism-ball-in-ptfe-pod) (the original V2 path) and as
the bench rig that characterises the sensing independent of the pivot choice.

```
                      +---------------------------------------+
   sensor pod         |              main board               |
  +--------------+    |                                       |
  | TMAG5273 x2  |-6p-|  ESP32-S3-MINI-1                      |
  | magnet, ball |    |   |- USB OTG ---- USB-C --> PC / XAC  |
  | force adjust |    |   |- BLE HID -------------> wireless  |
  +--------------+    |   |- ESP-NOW -----> dongle / ATOS S3  |
                      |   |- UART AS-Link -------> ATOS S3    |
  4x 3.5mm jacks -----|   |- WiFi AP -----> web config + OTA  |
  2x tactile ---------|                                       |
  sip/puff (opt) -----|  BQ24074 + MAX17048 (battery option)  |
                      |  WS2812 x2   DRV2605L + LRA (option)  |
                      +---------------------------------------+
```

---

## Sensor Pod

Tetra II flexure joint — isometric, front, side

### Mechanism

```
                topper (magnetic quick-swap, <1 g)
                  |
                  |   stick: carbon tube, 25/40/60 mm options
                  |
              [ P ]            remote rotation centre, ~50 mm out (set by flexure)
                  :
        ##########:##########   Tetra II spherical flexure (printed, one piece):
        ##  nested blade   ##   nested tetrahedron blade flexures, 3-DOF rotation
        ##  flexures       ##   about P, no sliding surfaces, elastic return to centre
        #####moving########      moving platform tilts 1:1 with the stick
            [N52 D4x2]           diametric sense magnet, rigid with the platform
                  |
         . . . . gap ~1.5 mm . . . .
       =============================    pod PCB
        [TMAG5273 A]   [TMAG5273 B]     dual 3D Hall, I2C
       =============================    fixed (flexure base mounts to it)
```

How it works, in one paragraph: the stick mounts to the flexure's moving platform and pivots
about the flexure's remote centre **P**. The blade flexures bend elastically, so they *are* the
pivot and the return-to-centre spring at once — there is no ball, no PTFE cup, no centering
magnet, and no force adjuster, and because nothing slides there is no break-away friction (the
first gram of input already moves it). The sense magnet rides the moving platform, so the field
*direction* at the sensors rotates 1:1 with stick angle (direction, not magnitude, so
temperature and gap creep calibrate out) — sensing is unchanged from the ball-pivot pod.

**Force is set by the flexure, not a dial.** Full-deflection force is fixed by blade geometry,
material, and scale, not adjusted with a thread. The paper's closed-form stiffness matches FEA
only qualitatively for the real tetrahedron element (NMAE ~35%), so treat any calculated figure
as a starting point and **measure force on the bench** (Phase 0). To retune, swap in a flexure
with different blade thickness or a scaled STEP (re-measure after any scale change — scaling
moves P and stiffens the blades non-linearly). Programmable force returns later via the Stage C
active-coil path (DESIGN_V2 section 5), not via the mechanism here.

### Pod parts

| Qty | Part | Spec | Notes | Est. |
|-----|---|---|---|---|
| 2 | TMAG5273A1 | 3-axis Hall, I2C, +/-40/80 mT | Two different factory I2C address variants (trailing letter of the orderable part number sets the default address; pick two distinct ones per the TI datasheet) | $1.60 |
| 1 | Sense magnet | N52 disc, D4 x 2 mm, **diametric** | On the flexure's moving platform. Diametric is load-bearing: axial will not work | $0.40 |
| 1 | Tetra II flexure | printed PLA/PETG, single piece, ~0.7 mm blade walls | The pivot **and** the centering spring; see [`models/tetra2-flexure/`](../models/tetra2-flexure/) (CC-BY) | print |
| 1 | Stick tube | carbon, ~2.5 mm OD | Kite/hobby stock; mounts to the flexure platform so its natural pivot sits at P | $0.50 |
| 1 | Pod PCB | 2-layer, ~20 x 20 mm | Flexure base mounts to it | $1.00 |
| 1 | Flexure mount / pod housing | printed | Locates flexure base over the PCB, sets the 1.5 mm magnet gap | print |
| 2 | Topper magnets | N52 D3 x 1 mm | One in stick, one per topper | $0.20 |

Dropped from the ball-pivot pod: the 4 mm ball, PTFE cup, ring centering magnet, steel
armature washer, and the M12 x 0.75 threaded force-adjuster carrier — the flexure replaces all
of them. They live on in the [alternative mechanism](#alternative-mechanism-ball-in-ptfe-pod).

### Pod connector (JST-SH 1.0 mm, 6-pin)

| Pin | Signal |
|-----|---|
| 1 | 3V3 |
| 2 | GND |
| 3 | SDA |
| 4 | SCL |
| 5 | INT_A (sensor A conversion-ready) |
| 6 | INT_B (sensor B conversion-ready) |

I2C at 400 kHz minimum, 1 MHz target. Keep the cable under ~30 cm for 1 MHz; chin-boom builds
with longer runs drop to 400 kHz (still comfortably supports 1 kHz sampling).

### Moving-mass budget (gravity bias, see DESIGN_V2 section 3)

The ball-pivot pod held the moving stick assembly under 2.5 g so a tilted-mount gravity bias
stayed below the centering force. The flexure changes the accounting: it has no ball or steel
washer, but its **moving platform and inner blades** add distributed mass that the old table did
not, and there is no adjustable centering to fight gravity with — the blades' fixed restoring
torque does. So re-derive the budget against the *measured* flexure stiffness in Phase 0.

| Part | Mass |
|---|---|
| Carbon tube (40 mm) | ~0.4 g |
| Sense magnet D4x2 | ~0.19 g |
| Topper + magnet | <1.0 g |
| Flexure moving platform + inner blades | measure (was 0 in ball-pivot accounting) |
| **Target** | keep gravity torque well under the flexure's restoring torque |

Weigh every new topper against this, and prefer stiffer-blade flexures for chin/vertical mounts
so the stick still returns to centre against gravity.

### Assembly targets

- Magnet-to-sensor gap: 1.5 mm nominal (1.0-2.5 mm usable; calibration absorbs the build)
- Stick's natural pivot aligned with the flexure's remote centre **P** (~50 mm out); the flexure
  base seated flat and square to the PCB so the moving platform tilts about P, not askew
- Sensors symmetric about the pivot axis, ~3 mm apart
- No ferromagnetic fasteners in the pod; brass or nylon M2 hardware
- Inspect blades after printing — a cracked or under-extruded blade changes stiffness and is a
  single-point failure (a blade break scraps the one-piece joint)

---

## Alternative mechanism: ball-in-PTFE pod

The original V2 pivot, retained as the fallback if printed-flexure creep/fatigue proves
unacceptable on the bench, and as the rig that characterises the sensing independent of the
pivot. The sensing, connector, and main board are identical to the flexure pod above.

```
            +-----o-----+      pivot: 4 mm ball in PTFE cup
            |   ball    |      (magnet preload seats it, ~30 gf)
            +-----+-----+
                  |
          [steel washer]       centering armature, rigid with stick
             [N52 D4x2]        diametric sense magnet, tilts 1:1 with stick
                  |
         . . . . gap ~1.5 mm . . . .
       =============================    pod PCB, dual TMAG5273
              (ring magnet on            centering force + ball preload,
               threaded carrier)         turn to set 1-8 gf
```

A ring magnet in a threaded carrier attracts a steel washer on the stick: on-axis the
attraction is pure preload seating the ball; tilted, it is a restoring torque. Turning the
carrier changes the gap, scaling centering force and preload together.

**Extra parts vs the flexure pod:** 4 mm steel/ceramic ball (grade 25, ~$0.30), PTFE cup
(machined 6 mm rod or printed PCTG seat + PTFE tape, ~$0.50), N52 ~D10/D5 x 2 mm axial ring
magnet (~$0.50), M3 steel armature washer (~$0.05), printed M12 x 0.75 carrier + housing with
quarter-turn detents.

**Force adjuster mapping** (characterize per build in Phase 0):

| Carrier position | Full-deflection force at 40 mm |
|---|---|
| Backed out (max gap) | ~1 gf, floaty |
| Nominal | 3 gf |
| Bottomed (min gap) | ~8 gf, near-isometric feel |

Moving-mass budget for this variant is the original <2.5 g (carbon tube ~0.4 g + sense magnet
~0.19 g + steel washer ~0.3 g + 4 mm ball ~0.26 g + topper <1.0 g ≈ 2.1 g; ceramic ball saves
~0.15 g). The build steps live in [ASSEMBLY.md](ASSEMBLY.md) and the printable parts in
[`models/`](../models/README.md) (Pod v0).

---

## Main Board

### Core

| Block | Part | Notes |
|---|---|---|
| MCU | ESP32-S3-MINI-1-N8 | Native USB OTG, BLE 5, WiFi; same target as ATOS |
| USB | USB-C 16-pin (TYPE-C-31-M-12 class) | 5.1k CC pulldowns, device role |
| USB ESD | USBLC6-2SC6 | On D+/D- |
| Regulator | RT9080-33 (or ME6217C33) | 3V3, low IQ |
| Jacks | 4x PJ-320A (TRRS footprint) | Wired tip+sleeve as mono switch inputs; ring routed to a test pad, reserved for future TRS analog accessories |
| Buttons | 2x 6 x 6 mm tactile | Mode/pair/tare combos |
| Status LEDs | 2x WS2812B-2020 | Keep >=15 mm from the pod |
| Expansion | 1x Qwiic/STEMMA-QT (JST-SH 4-pin) | Shares I2C0 |

### Options (fit the footprints, populate as needed)

| Block | Part | Notes |
|---|---|---|
| Charger | BQ24074 | Power-path: runs while charging, clean USB/battery switchover |
| Fuel gauge | MAX17048 | I2C, real state-of-charge |
| Battery | LiPo 503035, 500 mAh, JST-PH | Protected cell |
| Power switch | SS12D00 slide | In battery path |
| Sip/puff | MPXV7002DP (+/-2 kPa differential, analog) | Or Honeywell ABP I2C variant on the Qwiic port |
| Haptics | DRV2605L + 8 mm LRA | Mount the LRA in the base mass, isolation grommet, far side from the pod: it contains a magnet and it shakes |

### Pin assignments (draft, final at schematic review)

| Function | GPIO | Type | Notes |
|---|---|---|---|
| I2C0 SDA | 8 | I2C | Pod, fuel gauge, haptic, Qwiic; 2.2k pullups |
| I2C0 SCL | 9 | I2C | |
| Pod INT_A | 10 | Input | Conversion-ready, sensor A |
| Pod INT_B | 11 | Input | Conversion-ready, sensor B |
| Jack 1-4 | 4 / 5 / 6 / 7 | Input | 10k pullup + 100 nF + ESD |
| Button 1-2 | 12 / 13 | Input | Internal pullup |
| Haptic EN | 14 | Output | DRV2605L enable |
| Sip/puff | 1 | ADC1_CH0 | Analog option, RC filtered |
| AS-Link TX / RX | 17 / 18 | UART1 | To ATOS host, 1 Mbaud |
| WS2812 | 48 | Output | |
| USB D- / D+ | 19 / 20 | USB | Fixed function |

Strapping pins 0, 3, 45, 46 are left unconnected or output-only.

### 3.5 mm jack wiring (XAC-style switch inputs)

```
        +-----+
  Tip --|     |-- GPIO (10k pullup to 3V3, 100 nF to GND, ESD diode)
 Ring --|     |-- test pad (reserved)
Sleeve--|     |-- GND
        +-----+

Switch closed: GPIO LOW.  Debounce in firmware, 10-100 ms configurable.
```

---

## Power

| Mode | Source | Est. draw | Runtime |
|---|---|---|---|
| USB wired | 5 V USB-C | 80-120 mA typ (WiFi off) | n/a |
| BLE on battery | 500 mAh LiPo | 30-45 mA avg | ~11-16 h (validate in Phase 0) |
| ESP-NOW on battery | 500 mAh LiPo | similar to BLE | similar |
| Config mode (WiFi AP) | either | up to 500 mA peaks | keep on USB |

Battery path: USB-C -> BQ24074 (power path + charge) -> 3V3 LDO; MAX17048 on I2C for
state-of-charge; slide switch between cell and system. USB-only builds omit all three parts.

---

## Bill of Materials

### Core (wired build, ~$22)

| Item | Part | Est. |
|---|---|---|
| MCU module | ESP32-S3-MINI-1-N8 | $3.50 |
| Hall sensors | 2x TMAG5273A1 (distinct address variants) | $1.60 |
| Magnets | sense + topper set (no ring centering magnet) | $2.00 |
| USB-C + ESD + LDO + passives | | $2.50 |
| Jacks | 4x PJ-320A | $1.60 |
| Buttons, LEDs, connectors | | $1.50 |
| PCBs | main + pod, JLCPCB 2-layer | $4.00 |
| Pivot hardware | brass/nylon M2-M3 (flexure is printed) | $0.50 |
| Printed parts | PLA/PETG incl. Tetra II flexure, ~70 g | $3.50 |

The ball-in-PTFE pod adds ball + PTFE + ring magnet + carrier (~$3.35); see the
[alternative mechanism](#alternative-mechanism-ball-in-ptfe-pod).

### Options

| Option | Parts | Est. |
|---|---|---|
| Battery | LiPo 503035 + BQ24074 + MAX17048 + switch | +$13 |
| Sip/puff | MPXV7002DP + tubing + mouthpiece | +$10 |
| Haptics | DRV2605L + LRA | +$4 |
| ESP-NOW dongle | minimal second S3 board | +$9 |

---

## PCB Guidelines

| Parameter | Main board | Pod |
|---|---|-----|
| Layers | 2 | 2 |
| Thickness | 1.6 mm | 1.0 mm (fits the gap stack) |
| Copper | 1 oz | 1 oz |
| Finish | HASL ok | ENIG preferred (flat under sensors) |

1. **Pod:** solid ground pour, sensors on top, connector on bottom edge, no switching
   regulators or LEDs on the pod, panelize 4-up.
2. **Magnetic keep-out:** WS2812s, the LRA, and any speaker >=15 mm from the pod. Static
   fields calibrate out; switched currents and moving magnets do not.
3. I2C pullups 2.2k for 1 MHz operation.
4. 100 nF decoupling at every IC, bulk 10 uF at the module.
5. USB D+/D- as a 90-ohm differential pair, short.
6. Test points: 3V3, GND, SDA, SCL, AS-Link TX/RX.

---

## Safety Notes

- **Small magnets** are an ingestion hazard; glue all press-fit magnets (cyanoacrylate) and
  note them in the assembly guide.
- NdFeB is brittle: press by hand pressure only, never hammer.
- People with **pacemakers/implants** should follow their device manufacturer's magnet
  distance guidance; the fields here are small but real.
- LiPo: protected cells only, no charging unattended, observe polarity at the JST-PH.
- Mount securely (AMPS pattern / 1/4-20 insert); a falling unit near medical equipment is the
  failure mode that matters.

---

## Sourcing

| Part class | Source |
|---|---|
| ICs, passives, connectors | LCSC (JLC assembly compatible), Digi-Key for one-offs |
| Magnets | K&J Magnetics (spec-true), AliExpress (verify with a gauss meter or accept lot-to-lot spread; calibration absorbs most of it) |
| Ball, PTFE rod | McMaster-Carr, or bearing suppliers on AliExpress |
| Carbon tube | Hobby/kite shops |
| PCBs | JLCPCB |

---

## Validation

Every number above with "validate" or "characterize" next to it is a checkbox in
[TODO.md](../TODO.md) Phase 0. The pod's exit criteria (force, breakout, noise, latency,
drift, cycle life) are in [DESIGN_V2.md](DESIGN_V2.md) section 10.

## Next Steps

1. Phase 0 bench items (TODO.md)
2. Pod schematic + layout, panelized
3. Main board schematic + layout
4. Order boards + magnets together; calibration sweep on first articles
5. Print the Tetra II flexure, measure full-deflection force on the gram gauge, and iterate
   blade thickness / scale until the nominal feel target is met (bench, not calculated)

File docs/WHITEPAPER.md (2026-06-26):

# Alpha Stick: A Sub-5-Gram-Force, Open-Source Adaptive Joystick

**Owen Kent** | Alpha Stick Project | June 2026 | Draft 1.0

Firmware MIT, hardware CERN-OHL-P v2. Repository: github.com/owenpkent/alpha-stick

> **Mechanism update (June 2026):** the primary pivot is now the **Tetra II spherical flexure**
> — bearing-free, frictionless, and self-centering (see [DESIGN_V2.md](DESIGN_V2.md) section 5 and
> [`models/tetra2-flexure/`](../models/tetra2-flexure/)). The ball-in-PTFE pivot and the magnetic
> "force is a dial" adjuster described in the sections below are retained as the documented
> alternative/fallback; the contactless dual-Hall sensing, electronics, and force/latency targets
> are unchanged.

---

## Abstract

Standard game controller thumbsticks require 150 to 450 grams-force to
deflect, which excludes many people with neuromuscular conditions from both
gaming and, increasingly, from computer access in general. Devices that solve
the force problem exist but are expensive, proprietary, and single-purpose.
This paper presents Alpha Stick, an open-source joystick designed from first
principles to operate below 5 grams-force at roughly $25 in parts. Three
decisions follow from a force budget at the gram scale: position must be
sensed without contact (a tilting magnet read by Hall-effect sensors, using
field direction rather than magnitude for stability against temperature and
mechanical creep), the restoring force must be frictionless and adjustable
(magnetic attraction through a threaded carrier, 1 to 8 grams-force without
tools), and the only mechanical contact (the pivot) must contribute under 0.2
grams-force of friction. The same hardware enumerates as a USB/Bluetooth
gamepad, mouse, and keyboard, and a dual-sensor build with a TTL- and
sequence-guarded protocol allows it to serve as a drive input for the ATOS
open wheelchair platform under that system's safety authority. The design,
electronics, firmware architecture, and a falsifiable validation plan are
described; bench results are explicitly not yet claimed.

---

## 1. Introduction

The hardest part of any assistive technology setup is the input device. It is
the component that must match an individual body, the component that wears,
and the component whose commercial versions cost the most relative to what
they contain. For gaming specifically, the analog stick is the gateway: most
modern games are unplayable without smooth two-axis analog input.

The author is a wheelchair user with muscular dystrophy. The force floor of
commercial input devices is not an abstraction in this work; it is the
difference between playing and watching.

Alpha Stick's thesis is that the force problem is a physics problem, not a
product-tier problem. Solving it requires removing springs, potentiometers,
and sliding contacts from the force path entirely, and once that is done, the
remaining device is cheap. The project goal is a joystick that:

- deflects fully at under 5 grams-force, adjustable down to 1,
- costs about $25 in parts and is buildable with a 3D printer and a
  soldering iron,
- is one device for gaming (gamepad), desktop access (mouse and keyboard),
  and mobility (wheelchair drive input via a safety host),
- is fully open: hardware, firmware, and the reasoning behind both.

## 2. Background and prior art

Four existing systems define the landscape:

**QuadStick** is the reference mouth-operated controller: sip/puff plus a
low-force stick, multi-platform, and genuinely life-changing for its users.
It is also a single-vendor product at several hundred dollars.

**The Feather joystick (Celtic Magic)** demonstrated that sub-5-grams-force
operation with magnetic sensing is achievable and valuable, and is the
closest spiritual ancestor of this work. It remains a niche commercial
product rather than an open platform.

**The Xbox Adaptive Controller and PlayStation Access controller** solved
the hub problem: standardized 3.5 mm switch jacks and USB stick ports that
adaptive devices can plug into. They deliberately do not solve the analog
stick itself; both expect third-party sticks, which is the slot Alpha Stick
fills.

**Isometric (force-sensing) sticks**, from the TrackPoint to load-cell
designs, including this project's own v1 concept, eliminate motion entirely.
Section 4 explains why sustained-force input was rejected on fatigue grounds
in favor of small displacement at near-zero force.

The gap is a device that is simultaneously ultra-low-force, low-cost, open,
multi-role, and documented well enough to be built and modified by its users.

## 3. Requirements

| # | Requirement | Target |
|---|---|---|
| R1 | Full-deflection force | <5 gf, nominal 3 gf, adjustable 1-8 gf at a 40 mm grip point |
| R2 | Throw | +/-4 to 6 degrees (+/-2.8 to 4.2 mm at 40 mm) |
| R3 | Breakout force (first motion) | <0.5 gf |
| R4 | Sensing | Contactless; no pots, no strain gauges in the force path |
| R5 | Wired latency, motion to USB report | <5 ms |
| R6 | Effective resolution | >=8 bits per axis at 1 kHz |
| R7 | Core bill of materials | <$35 |
| R8 | Build accessibility | FDM printer plus basic soldering; no machining |

## 4. The force budget: designing at the gram scale

At 3 grams-force full scale, effects that are negligible in a normal joystick
become the design. The budget at the 40 mm grip point:

| Source | Allocation | Mechanism |
|---|---|---|
| Centering (the intended force) | 1.0-8.0 gf, nominal 3.0 | Magnetic attraction, adjustable gap |
| Pivot friction | <0.2 gf | PTFE-class contact, ~30 gf preload, 2 mm effective radius: friction torque is approximately mu * N * r = 0.075 * 30 gf * 2 mm = 4.5 gf-mm, or ~0.11 gf at the grip point |
| Seals and boots | 0 | Labyrinth gap; any contacting seal would exceed the friction budget on its own |
| Sensor | 0 | Contactless |
| Gravity bias | up to ~1.3 gf equivalent | Bounded by a moving-mass budget, corrected by a per-profile tare |

Two consequences are worth stating because they shaped everything else.

**Gravity is a first-order term.** A moving assembly of mass m with center of
gravity h above the pivot, mounted horizontally (a chin boom, a vertical
surface), experiences a constant torque m * g * h. At m = 2.5 g and
h = 20 mm this is 50 gf-mm, about 1.25 gf at the grip point, nearly half the
nominal centering force. The design therefore carries a hard moving-mass
budget of 2.5 g (carbon tube, hollow toppers under 1 g each, one small
magnet), a firmware mount-orientation tare stored per profile, and a
recommendation to run tilted mounts at a stiffer force setting.

**Sustained force is the wrong currency.** The project's v1 concept was an
isometric stick (four load cells, no motion), reasoning that zero motion
means zero range-of-motion demands. The flaw is physiological: an isometric
stick converts every held input into a continuously held force, which is
precisely what fatigues users with neuromuscular conditions. It also
sacrifices proprioceptive feedback and inherits strain-gauge drift, so the
center wanders with temperature. A small displacement (2 to 3 mm) at
near-zero force preserves the minimal range-of-motion benefit while letting
the user rest at a held position, and a stiff force setting approximates the
isometric feel for those who want it. The load-cell design is archived in
this repository with its parts list for anyone who wants to pursue it.

## 5. Sensing: measuring direction, not magnitude

A diametrically magnetized disc magnet (N52, 4 x 2 mm) is fixed to the
moving assembly and tilts 1:1 with the stick. One or two 3-axis Hall-effect
sensors (TI TMAG5273, I2C, roughly $0.80 each) sit 1.5 mm below it and
measure the field vector at 1 kHz with 8x averaging.

The estimator uses the **direction** of the field vector, not its magnitude,
mapped through a one-time calibration polynomial. This is the load-bearing
trick for a printed, glued, hobby-buildable device, because field direction
is first-order immune to:

- NdFeB temperature coefficient (about -0.12 %/degC affects magnitude, not
  direction),
- axial creep of printed parts (the gap changes magnitude, not direction),
- magnet strength tolerance between builds and suppliers.

All ferromagnetic parts move rigidly with the magnet, so their distortions
are constant in the stick frame and the calibration absorbs them.

Three further properties come free:

**A zero-force click.** Pressing the stick down compresses the pivot contact
and closes the magnet-sensor gap; the magnitude channel, useless for tilt, is
ideal for detecting this. The result is a press-to-click at the stick's own
sub-5-gram force with no switch in the force path, plus lift-off detection.

**Cheap redundancy.** A second TMAG5273 (a different factory I2C address
variant) reads the same magnet. The gaming build averages them; the drive
build (section 10) cross-checks them continuously and latches a fault on
disagreement. Drive-grade input plausibility for about $1.

**An honest noise story.** With a 40-100 mT bias field and +/-5 degrees of
rotation, the per-axis signal swing is +/-3.5 to 8 mT against sensor noise in
the tens of microtesla after averaging: an estimated 8 to 9 effective bits
per axis at 1 kHz, comparable to commercial thumbsticks, with the 16-bit
MLX90393 as a drop-in upgrade path if the bench disagrees. These are
estimates pending measurement (section 12).

## 6. Mechanism: constrained passive magnetics

Earnshaw's theorem (1842) rules out stable static levitation with permanent
magnets alone, so every "floating" joystick is actually a constraint plus a
force field. Alpha Stick embraces that split explicitly:

- **The constraint** is a single pivot: a hardened ball (or printed dome) in
  a PTFE-lined socket. A gimbal was rejected because four sliding contacts
  dominate feel at the gram scale; a flexure was rejected as the primary
  element because flexure stiffness is a spring whose printed-polymer creep
  moves the center over weeks.
- **The force field** is magnetic attraction between the moving assembly and
  a ring magnet (or steel armature) held in a **threaded carrier** beneath
  the sensor. On axis, the attraction is pure preload that seats the pivot;
  tilted, it is a restoring torque. The full-deflection torque required is
  small (3 gf at 40 mm is about 1.2 mN-m), well within reach of small N52
  parts at millimeter gaps.

Turning the carrier changes the working gap, which scales preload and
centering force together: a tool-free force dial from about 1 to 8
grams-force. For users whose strength varies day to day, this single
mechanical feature may matter more than any firmware option.

There are no springs, no potentiometers, no sliding electrical contacts, and
no parts that wear except a PTFE surface. The moving assembly is about 2.1 g
against the 2.5 g budget.

## 7. Electronics

The system is deliberately boring: an ESP32-S3 module (native USB OTG,
Bluetooth LE, WiFi), the Hall sensor pair on a 20 x 20 mm satellite pod PCB
connected by a 6-pin cable, four 3.5 mm jacks for the standard adaptive
switch ecosystem, USB-C with proper ESD protection, and optional blocks for
battery (power-path charger and fuel gauge), sip/puff pressure sensing, and a
haptic driver for non-visual confirmation. The pod-on-a-cable split matters:
the same input mechanism drops into a desktop base, a chin boom, a
mouth-stick frame, or a thumb puck without electronics changes.

Core BOM is approximately $22 (MCU module $3.50, both sensors $1.60, magnets
$2.50, the rest connectors, passives, PCBs, and printed parts). Battery,
sip/puff, and haptics add $13, $10, and $4 respectively.

## 8. Firmware

The firmware (ESP-IDF, FreeRTOS) is one composite input device with
switchable personalities. A 1 kHz sensing task reads both sensors, applies
the calibration map and processing pipeline, and publishes to a lock-free
latest-value mailbox; a router task maps the active mode onto USB HID
(gamepad, mouse, and keyboard report IDs in one never-re-enumerating
composite device), BLE HID (same reports), ESP-NOW (low-latency wireless to a
dongle), or the AS-Link wired protocol (section 10).

The pipeline order is: calibration map, mount-orientation tare, axis
rotation, radial deadzone (preserves diagonals), per-mode response curve,
adaptive smoothing, optional slew limiting, dithered 16-bit quantization.
Tremor handling uses the 1-euro filter (Casiez et al., CHI 2012), whose
cutoff rises with input speed so rest tremor is smoothed without adding lag
to deliberate motion, plus an optional 3-12 Hz notch for rhythmic intention
tremor. Wired motion-to-report latency budgets to 2-3 ms.

Configuration is a JSON profile system (deadzone, curves, filters, mappings,
mount tare) stored on-device, edited through a WiFi web UI or a WebSerial
channel, with profiles switchable from hardware. Updates are A/B OTA with
automatic rollback.

## 9. Accessibility as architecture

Several features that read as accessibility checkboxes are, in this design,
direct consequences of the architecture:

- **Dwell click**: in mouse mode the pointer resting within a small radius
  fires a click, so the device is fully usable with zero clicking force.
- **Z-press click**: the same sub-5-gram force as travel, from the magnitude
  channel, no switch.
- **Sip/puff as four buttons**: hard/soft sip and puff thresholds, the
  QuadStick convention, available in every mode.
- **The force dial**: strength varies day to day; the input device should
  too, without tools or settings menus.
- **Per-profile mount tare**: chin and vertical mounts are first-class, not
  an afterthought fighting gravity bias.
- **One stable USB identity**: mode switches never re-enumerate, because
  re-pairing and driver churn are themselves accessibility failures.

## 10. Wheelchair drive input and the ATOS integration

ATOS is an open, mixed-criticality platform for powered wheelchairs (part of
the RAMMP research program) whose Layer 1 is an ESP32-S3 safety node: a
non-swappable motor-control core plus capability-gated loadable modules that
may only *propose* motion ({linear, angular, TTL, sequence} structures the
host clamps and may ignore). ATOS's architecture documents design input-device
integration but no input device has been built for it.

Alpha Stick is designed to be that device, under a strict division of
authority: **the stick proposes, the ATOS host disposes.** The stick never
touches motors, never carries stop authority, and is treated by the host as
untrusted input subject to validation.

The integration is a 20-byte framed protocol (AS-Link) over UART or ESP-NOW
whose semantics deliberately mirror the ATOS proposal type: normalized Q15
axes, a TTL the receiver decays to zero on staleness, a monotonic sequence
number, health flags, and a CRC32, plus a 1 Hz health frame whose absence
marks the input dead regardless of data frames. On the ATOS side, a thin
gateway module (L3 command tier) maps frames to drive proposals through the
host's own curves and limits.

Driving is a different integrity domain from gaming, so it is a different
**build**, not a different setting: the drive build makes the dual-sensor
cross-check mandatory (disagreement beyond 3% of full scale for 50 ms latches
a zero-output fault recoverable only at neutral with explicit
acknowledgment), disables automatic re-centering entirely, holds output at
zero on boot until the stick is observed neutral, enables slew limiting by
default, and shuts down WiFi and BLE in wired mode. The design posture
follows ISO 7176-14 (power wheelchair control systems) as a reference
standard; no compliance is claimed, and the final safety envelope always
belongs to the ATOS host's limit governor.

## 11. Stage C: active magnetics (research direction)

Because the centering field is magnetic, it can eventually be electronic:
four planar coils in the pod PCB layers, driven closed-loop at 1 kHz from the
same Hall sensors, superimpose forces on the stick magnet. The required
full-scale torque (~1.2 mN-m) is small enough that this is plausible but not
yet demonstrated; the stage begins with a single go/no-go coil-force bench.

If it works, the payoff is a programmable force field no commercial adaptive
joystick offers: centering force set in firmware per profile (0 to ~10 gf),
virtual detents and walls, haptic confirmation ticks, and **active tremor
damping**, a velocity-proportional opposing force applied at the physical
layer rather than as filtering, with the passive behavior as the failure
fallback. Power (~100-300 mW active) makes this a wired or docked feature
first.

## 12. Validation methodology and current status

This project's credibility strategy is to publish targets before results.
As of June 2026: the design baseline, firmware scaffold, and a parametric
printable bench rig are complete; **no bench measurements have been taken
yet**. The Phase 0 plan measures, in order: Hall signal swing, noise, and
effective bits at 1 kHz; centering force versus carrier position (target
range 1-8 gf, gauge-verified); pivot breakout force (<0.5 gf) and
return-to-center repeatability; moving mass; and end-to-end wired latency
(<5 ms, logic-analyzer-verified). Stage A exit criteria additionally include
center drift under 1% of full scale over two hours, a 100k-cycle deflection
test, and the only metric that finally matters: daily use by the author for
gaming and desktop work.

Estimates in this paper that fail on the bench will be corrected in the
design documents with the measured values and reasoning, in public.

## 13. Cost and reproducibility

The entire device is reproducible from the repository: a parametric OpenSCAD
source generates the printable mechanism; the PCB design targets common
fabrication services; the firmware builds with the standard Espressif
toolchain; and the documentation set covers hardware, assembly, printing,
configuration, and the development workflow itself. Core cost is ~$22 plus
roughly 100 g of filament. No part requires machining, and the only
specialized assembly skill is gluing small magnets in the correct
orientation, which the assembly guide treats with appropriate paranoia.

## 14. Limitations and open problems

Honest unknowns, with their planned resolutions:

1. **Sensor SNR** may fall below 8 effective bits at +/-5 degrees (first
   bench item; MLX90393 fallback footprint exists).
2. **PTFE stiction** may be perceptible below 1 gf (breakout measured
   explicitly; jewel-bearing fallback identified).
3. **Magnetic centering force range** at the available gaps is estimated,
   not yet gauge-verified (the bench rig's entire purpose).
4. **Printed-thread quality** for the force adjuster varies by printer
   (documented tuning parameter; metal-insert fallback).
5. **Platform compatibility** beyond PC (XAC USB stick ports, Switch BLE) is
   designed-for but unverified (early Phase 0 test).
6. **ATOS-side host service** for external input streams does not exist yet
   in the ATOS ABI (proposed as a capability addition; the gateway can be
   prototyped against a host stub).
7. **Stage C coil force** is plausible on paper only.

## 15. Roadmap

Stage A "Glide": the core stick, USB and BLE, web configuration, bench-passed
exit criteria. Stage B "Bridge": the ecosystem release: switch jacks,
sip/puff, chin/mouth/thumb bodies, the ESP-NOW dongle, AS-Link and the ATOS
gateway prototype, platform verification, kits. Stage C "Field": the active
coil layer, beginning with its feasibility bench.

## 16. Conclusion

The adaptive input problem is usually attacked as a product problem, which
produces excellent $400 devices. Treating it as a physics problem (remove
every contact and every spring from the force path, then measure direction
instead of magnitude so cheap materials stay stable) produces a $25 device
that is also a better architecture: the same contactless core scales from a
gaming stick to a mouse to a redundant, protocol-guarded wheelchair input.
Everything here is open, and everything here is falsifiable on a workbench,
which is where it goes next.

## Acknowledgments

The disability gaming community, AbleGamers, SpecialEffect, and Makers Making
Change for advocacy and groundwork; the QuadStick and Feather projects for
proving the categories; the ATOS/RAMMP program for the safety architecture
this design integrates with.

## References

- QuadStick: quadstick.com
- Feather joystick, Celtic Magic: celticmagic.org/feather
- Xbox Adaptive Controller: xbox.com/accessories/controllers/xbox-adaptive-controller
- PlayStation Access controller: playstation.com/accessories/access-controller
- ATOS repository and Layer 1 whitepaper (module ABI, drive proposals)
- S. Earnshaw, "On the nature of the molecular forces..." Trans. Camb. Phil. Soc., 1842 (Earnshaw's theorem)
- G. Casiez, N. Roussel, D. Vogel, "1 € Filter: A Simple Speed-based Low-pass Filter for Noisy Input in Interactive Systems," CHI 2012
- ISO 7176-14, Wheelchairs: Power and control systems for electrically powered wheelchairs and scooters
- TI TMAG5273 datasheet; Melexis MLX90393 datasheet
- This repository: DESIGN_V2.md (working baseline), HARDWARE.md, FIRMWARE.md, BENCH_LOG.md

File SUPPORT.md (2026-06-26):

# Getting help

Thanks for trying Alpha Stick. Here is the fastest way to get unstuck.

## Where to ask

| You want to... | Go to |
|---|---|
| Ask a question, share a build, float an idea | [Discussions](https://github.com/owenpkent/alpha-stick/discussions) |
| Report a bug (firmware, tools, docs) | [Bug report](https://github.com/owenpkent/alpha-stick/issues/new?template=bug_report.yml) |
| Request a feature | [Feature request](https://github.com/owenpkent/alpha-stick/issues/new?template=feature_request.yml) |
| Share a print or bench result | [Build & bench report](https://github.com/owenpkent/alpha-stick/issues/new?template=build_report.yml) |
| Give accessibility feedback | [Accessibility feedback](https://github.com/owenpkent/alpha-stick/issues/new?template=accessibility_feedback.yml) |
| Report a security or safety issue | Privately — see [SECURITY.md](SECURITY.md) |

## Before you post

- Skim the [Executive Summary](docs/EXECUTIVE_SUMMARY.md) and the relevant guide:
  [HARDWARE](docs/HARDWARE.md), [FIRMWARE](docs/FIRMWARE.md),
  [PRINTING](docs/PRINTING.md), [ASSEMBLY](docs/ASSEMBLY.md), or
  [CONFIGURATION](docs/CONFIGURATION.md).
- Search existing [issues](https://github.com/owenpkent/alpha-stick/issues) and
  [discussions](https://github.com/owenpkent/alpha-stick/discussions) first.
- Include specifics: for firmware, your ESP-IDF version and board; for prints,
  your printer, material, and slicer settings; for bench results, your
  measurement method and numbers.

This is a volunteer project in Phase 0 — please be patient and specific.
Accessibility feedback from people with disabilities is the most valuable input
we get; it outranks every estimate in the repo.

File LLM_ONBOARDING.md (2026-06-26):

# LLM Onboarding

Quick reference for AI assistants working on Alpha Stick.

---

## Project Overview

**Name:** Alpha Stick  
**Purpose:** Open-source adaptive gaming joystick using ESP32 and 3D printing  
**Status:** Planning / Early Development

---

## About the Owner

I'm Owen — a wheelchair user with muscular dystrophy.

- **Typing is hard** — Be proactive. Make decisions. Don't ask for confirmation on small things.
- **Offer A/B/C choices** — I can type one letter instead of explaining.
- **PowerShell on Windows** — Use PowerShell syntax. Prefer single-line commands.
- **Accessibility matters** — This project is a tool I actually need.

---

## Project Goals

1. **Affordable** — Target BOM under $50
2. **Open Source** — Hardware, firmware, and docs freely available
3. **Customizable** — Modular, adaptable to different disabilities
4. **Compatible** — Works with Xbox Adaptive Controller, PC, and Project Nimbus
5. **Updateable** — OTA firmware updates

---

## Key Files

| File | Purpose |
|---|---|
| `README.md` | Project overview, features, quick start |
| `TODO.md` | Task tracking with checkboxes |
| `docs/EXECUTIVE_SUMMARY.md` + `docs/WHITEPAPER.md` | External-facing: pitch and technical narrative |
| `docs/WORKFLOW.md` | Development loops, change-propagation rules, commands |
| `docs/DESIGN_V2.md` | V2 design baseline: rationale, budgets, roadmap |
| `docs/HARDWARE.md` | Build reference: parts, pins, wiring, BOM |
| `docs/FIRMWARE.md` | Firmware architecture (ESP-IDF), build instructions |
| `docs/PRINTING.md` | 3D printing guide and settings |
| `firmware/sdkconfig.defaults` | ESP-IDF build configuration |
| `firmware/main/main.cpp` | Firmware entry point |
| `models/stl/` | Ready-to-print 3D models |

---

## Tech Stack

- **Microcontroller:** ESP32-S3 (USB HID + Bluetooth LE)
- **Framework:** ESP-IDF 5.x (TinyUSB + NimBLE); moved off Arduino/PlatformIO in V2
- **Protocols:** USB composite HID, BLE HID, ESP-NOW, UART AS-Link (ATOS), WiFi (for config)
- **3D Modeling:** FreeCAD or Fusion360
- **PCB Design:** KiCad or EasyEDA

**V2 design baseline:** `docs/DESIGN_V2.md` is the source of truth (Tetra II spherical flexure
pivot with built-in elastic self-centering, contactless dual-Hall sensing, <5 gf force target,
sensor pod architecture). The ball-in-PTFE pod with a magnetic force adjuster is the documented
alternative/fallback. HARDWARE.md and FIRMWARE.md match it. ISOMETRIC_PARTS.md is archived.

---

## Related Project: Project Nimbus

Alpha Stick integrates with [Project Nimbus](https://github.com/owenpkent/Project-Nimbus):

- **Location:** `C:\Users\Owen\dev\Project-Nimbus`
- **Purpose:** Virtual controller interface using vJoy
- **Integration:** Alpha Stick provides physical input, Nimbus adds on-screen controls
- **Shared concepts:** Sensitivity curves, deadzone, profile system

---

## Conventions

### Commit Messages
```
feat: add new feature
fix: correct bug
docs: update documentation
refactor: restructure code
chore: maintenance tasks
```

### Code Style
- ESP32 firmware: C++ on ESP-IDF 5.x (FreeRTOS tasks, components)
- Web config: HTML/CSS/JS (vanilla, no frameworks)
- Python scripts: PEP 8

### File Naming
- Lowercase with hyphens: `alpha-stick`, `web-config`
- STL files: `enclosure-base-v1.stl`
- Source files: `main.cpp`, `joystick.h`

---

## Hardware Components

| Component | Recommended Part | Purpose |
|---|---|---|
| MCU | ESP32-S3-MINI-1 (DevKitC for bench) | Main controller |
| Pivot + centering | Tetra II spherical flexure ([`models/tetra2-flexure/`](models/tetra2-flexure/)) | Bearing-free joint + elastic self-centering; force set by blade geometry |
| Position sensing | 2x TMAG5273 3D Hall + N52 diametric magnet | Contactless, <5 gf stick |
| Buttons | 6mm tactile | Direct input |
| Jacks | PJ-320A 3.5mm | External switches |
| Case | 3D printed PLA/PETG | Enclosure + sensor pod bodies |

---

## Quick Commands

```powershell
# Build firmware (ESP-IDF PowerShell)
cd C:\Users\Owen\dev\alpha-stick\firmware; idf.py build

# Flash and monitor
idf.py -p COM5 flash monitor

# Open in VS Code
code C:\Users\Owen\dev\alpha-stick
```

---

## Inspiration Products

| Product | Website | Key Features |
|---|---|---|
| QuadStick | quadstick.com | Mouth-operated, sip/puff |
| Feather | celticmagic.org/feather | Ultra-light force, magnetic |
| Xbox Adaptive | xbox.com | 3.5mm jacks, USB hub |
| PS Access | playstation.com | Swappable caps, profiles |
| Titan Two | consoletuner.com | Cross-platform, scripting |

---

## Current Focus

Phase 1: Foundation
1. Define hardware requirements
2. Select components
3. Create initial 3D model
4. Basic firmware scaffold

See `TODO.md` for detailed task tracking.

---

## Constellation

This repo is tracked by [Constellation](https://github.com/owenpkent/constellation).

For dashboard integration:
1. `README.md` with `## Status` section ✅
2. `TODO.md` with checkbox items ✅
3. Add to Constellation's `projects.yaml`

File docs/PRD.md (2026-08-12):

# Alpha Stick PRD (v0.1, first pass)

**One-liner:** An open-source, 3D-printable joystick that moves with under 5 grams of force, costs about $25 in parts, and works as a gamepad, a mouse, and (later) a wheelchair drive input.

**Owner:** Owen Kent | **Status:** Draft, Phase 0 (bench validation) | **Date:** August 2026
**Scope of this PRD:** Stage A "Glide" (the core stick). Stages B/C are out of scope, see [DESIGN_V2.md](DESIGN_V2.md) section 10.

---

## 1. Problem

A standard thumbstick needs 150 to 450 gf to deflect, which is a wall for people with muscular dystrophy, SMA, ALS, and similar conditions. Devices built for ultra-low force exist but cost $200 to $500+, are proprietary, and cannot be repaired, adapted, or replicated by the people who depend on them.

## 2. Target users

| Primary | Gamers with limited hand strength or range who can produce a few grams of force and millimeters of travel |
|---|---|
| Secondary | Makers, OTs, and assistive tech builders who fit devices to a specific person |
| Tertiary | ATOS / RAMMP integrators who need an open input device for a wheelchair safety host |

## 3. Goals and non-goals

**Goals (Stage A):** ultra-low-force stick that anyone can print and solder; plug-and-play USB and BLE HID; browser-based configuration; honest, bench-measured specs.

**Non-goals (this release):** wheelchair drive certification or any safety claim; active-coil force feedback (Stage C); sip/puff and 3.5 mm jacks (Stage B); a manufactured/retail product; console-native Xbox or PlayStation wireless protocols.

## 4. Requirements

| # | Requirement | Target | Priority |
|---|---|---|---|
| R1 | Full-deflection force at 40 mm grip point | <5 gf, nominal ~3 gf | Must |
| R2 | Throw | +/-4 to 6 deg (+/-2.8 to 4.2 mm) | Must |
| R3 | Breakout force | <0.5 gf | Must |
| R4 | Sensing | Contactless dual Hall, one tilting magnet | Must |
| R7 | Wired stimulus-to-report latency | <5 ms | Must |
| R8 | Effective resolution | >=8 bits/axis at 1 kHz, >=9 filtered | Must |
| R9 | Core BOM | <$35 wired, <$50 with battery | Must |
| R10 | Buildable with FDM printer + soldering iron | No machining, no reflow required | Must |
| R11 | Modes | Gamepad + mouse composite HID, runtime switch | Must |
| R12 | Configuration | USB CDC + web UI: deadzone, curve, tremor filter, profiles | Must |
| R13 | Persistence and updates | NVS profiles, OTA with A/B rollback | Should |
| R14 | Z press-to-click | <5 gf with clean hysteresis | Should |
| R15 | Battery life on BLE | 10+ hours | Should |

## 5. Success metrics

- **Physics:** R1/R3/R7/R8 met on the bench and published in [BENCH_LOG.md](BENCH_LOG.md) with raw data.
- **Durability:** flexure holds center within spec after a 30-day soak and 100k-cycle fatigue run (creep is the top risk).
- **Buildability:** 3 external builders complete a stick from the docs alone without maintainer intervention.
- **Users:** 5+ people with disabilities test the device and report usable control in real gameplay.

## 6. Key risks

| Risk | Mitigation |
|---|---|
| Printed flexure creeps or fatigues at sub-5 gf | Soak/fatigue test early; ball-in-PTFE + magnet centering kept as the fallback pivot |
| Hall noise floor misses >=8 effective bits | Bench dual TMAG5273 first; MLX90393 as the alternative |
| Gravity bias on a 3 gf pivot in non-desktop orientations | Weigh the moving assembly, re-derive the budget, consider firmware bias trim |
| Console compatibility overpromised | Publish an honest platform matrix; route consoles via XAC/adapter, not native protocols |

## 7. Milestones

| Milestone | Exit criteria |
|---|---|
| M0 Bench proven | R1, R3, R8 measured on real hardware; pivot decision (flexure vs ball) locked |
| M1 Firmware spikes | USB composite HID + BLE HID streaming at 1 kHz; R7 measured |
| M2 Integrated prototype | Pod + main board + printed body working end to end as gamepad and mouse |
| M3 Beta build | Assembly guide, BOM with links, configurator, 3 external builds |
| M4 v1.0 | Success metrics met, tagged release, published to the accessibility maker community |

## 8. Open questions

1. Does the flexure survive creep, or does Stage A ship on the ball pod?
2. Is Z-click achievable on a flexure (axially stiff), or does it need a compliant mount or a discrete switch?
3. Single integrated board, or pod + main board split, given the multi-body goal?
4. Which single form factor ships first for v1.0: desktop base, chin boom, or thumb pad?

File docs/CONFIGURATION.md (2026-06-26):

# Configuration Guide

How to configure Alpha Stick **V2**: calibration, modes, sensitivity, filtering, and profiles.

With the primary **Tetra II flexure** pivot, full-deflection force is fixed by the printed part,
not a software setting — to change how hard the stick is to move you swap in a stiffer or softer
flexure. (The alternative ball-pivot pod adds a hardware **force adjuster**: turn the carrier
between detents to set 1-8 gf.) Everything else here is firmware and lives in profiles.

---

## Accessing Configuration

### Web UI (full configuration)

1. **Enter config mode:** hold Button 1 + Button 2 while plugging in USB
2. **Connect to WiFi:** SSID `AlphaStick`, password `configure`
3. **Open** `http://192.168.4.1`
4. Adjust, **Save**, **Restart**

### WebSerial (no WiFi needed)

The USB CDC interface speaks the same JSON config protocol. Any WebSerial-capable browser page
or a serial terminal can read/write settings while the device keeps working. Good for quick
tweaks and scripting.

### Desktop tools (implemented)

The native host tools in [tools/](../tools/) drive the USB CDC protocol today, no WiFi needed:

- **Configurator** (`python tools/configurator.py`): a GUI to change axes, deadzone, curve,
  filter, mouse speed, button mappings, and macros. Stick/mouse changes apply live.
- **Flasher** (`python tools/as_flash.py`): a developer CLI to flash firmware, erase, monitor,
  and read/push profiles.

Stick and mouse settings apply immediately. Button mappings and macros are authored and saved
now; the firmware runs them once the jack/sip-puff input subsystem lands. See
[tools/README.md](../tools/README.md).

---

## Calibration and Tare

Do this once per build, and again after any pod disassembly.

### Guided calibration sweep

Web UI -> Calibration -> Start. You will be asked to:

1. Leave the stick at rest (center hold)
2. Deflect to 8 compass points
3. Sweep one slow full circle at the rim

This fits the field-to-angle map. The live view should then reach the rim in all directions
with no flat spots. `cal_valid` shows green when the map is good.

### Mount tare (gravity bias)

If the unit is mounted tilted or vertical (chin boom, wheelchair rail), the stick's own weight
biases it. In the profile, run **Mount tare** with the unit installed at its real angle; the
offset is stored per profile, so a "desk" profile and a "chin" profile can coexist.

### Center tare rules

- Manual tare: hold Button 1 for 3 s (stick untouched), or web UI -> Tare
- Automatic tare happens only at boot, only if the stick has been still and near the stored
  center for 3 s. It never re-tares silently during use.

Tilted mounts: also consider a stiffer force setting (4-6 gf detents) so the stick returns
against gravity.

---
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

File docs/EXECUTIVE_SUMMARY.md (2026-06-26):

# Alpha Stick: Executive Summary

**An open-source gaming joystick that moves with less than 5 grams of force,
built from $25 of parts, that is also a mouse and a wheelchair input device.**

June 2026 | Owen Kent | MIT licensed firmware, CERN-OHL-P hardware

---

## The problem
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

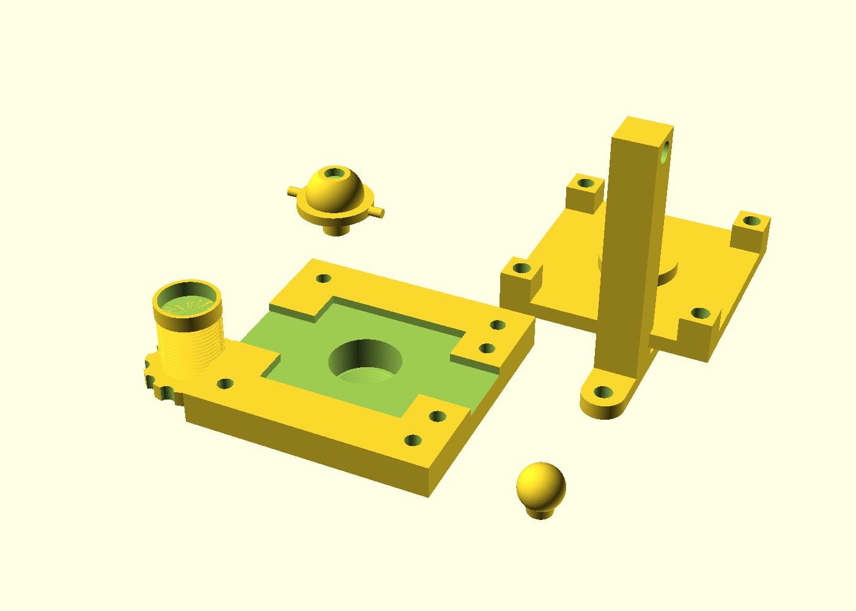
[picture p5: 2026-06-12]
models/pod-v0-plate.png

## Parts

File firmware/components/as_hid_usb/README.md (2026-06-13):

# as_hid_usb

TinyUSB composite USB device for Alpha Stick V2. Presents one HID interface that
carries three report IDs (gamepad, mouse, keyboard) plus a CDC ACM serial channel
for configuration. Mode switches change *which* reports stream; the descriptors are
constant, so the device never re-enumerates and the OS sees one stable device.

Architecture context is in [docs/FIRMWARE.md](../../../docs/FIRMWARE.md) (USB and BLE
HID section); the 16-bit report rationale is DESIGN_V2 requirement R8.

---

## USB layout

Composite device with an Interface Association Descriptor (CDC requires IAD), so the
device class is `MISC / COMMON / IAD`.

| Interface | Num | Endpoint(s) | Purpose |
|---|-----|---|---|
| HID | 0 | `0x81` IN | gamepad + mouse + keyboard reports |
| CDC notify | 1 | `0x82` IN | CDC ACM management |
| CDC data | 2 | `0x03` OUT, `0x83` IN | config channel bytes |

### Device descriptor

| Field | Value | Notes |
|---|---|---|
| idVendor | `0x303A` | Espressif's VID |
| idProduct | `0x4001` | **placeholder**, request a pid.codes PID before any public release |
| bcdDevice | `0x0200` | tracks hardware V2 |
| bcdUSB | `0x0200` | USB 2.0 full speed |

String descriptors: manufacturer "Alpha Stick Project", product "Alpha Stick",
serial "AS2-0001" (placeholder), HID interface "Alpha Stick HID", config interface
"Alpha Stick Config".

---

## Reports

### Report ID 1: gamepad (custom descriptor)

7-byte payload, little-endian, packed:

| Offset | Field | Type | Range | Maps to |
|---|---|---|---|---|
| 0 | X | int16 | -32767..32767 | stick X, post-pipeline |
| 2 | Y | int16 | -32767..32767 | stick Y |
| 4 | Z | uint8 | 0..255 | press axis |
| 5 | buttons | uint16 | bitfield, 16 buttons | Z-click, jacks, sip/puff |

16-bit axes are deliberate: an 8-bit stick quantizes the usable centre too coarsely
for tremor-filtered fine control (DESIGN_V2 R8). On the wire the report is 8 bytes
(1 report ID + 7 payload).

### Report ID 2: mouse

Stock `TUD_HID_REPORT_DESC_MOUSE`: 5 buttons, **int8** dx/dy, int8 wheel, int8 pan.
Sent via `tud_hid_n_mouse_report`.

### Report ID 3: keyboard

Stock `TUD_HID_REPORT_DESC_KEYBOARD` (standard 6KRO). The descriptor and report ID
are present, but there is no `usb_hid_send_keyboard` writer yet (see Known gaps).

---

## CDC config channel

`cdc_rx_callback` assembles received bytes into newline-delimited lines and hands each
to a handler registered with `usb_hid_set_cdc_line_handler`. The wiring in `main` points
that handler at the `as_config` JSON protocol (get/set/info/save/defaults/reboot), and
responses go back via `usb_hid_cdc_write`. The protocol and the host tools that drive it
are documented in [tools/README.md](../../../tools/README.md).

---

## Public API

```c
#include "as_hid_usb/usb_hid.h"

void usb_hid_init(void);   // install TinyUSB driver + CDC ACM; ESP_ERROR_CHECK on failure
bool usb_hid_ready(void);  // tud_mounted() && HID instance 0 ready

bool usb_hid_send_gamepad(int16_t x, int16_t y, uint8_t z, uint16_t buttons);
bool usb_hid_send_mouse(uint8_t buttons, int8_t dx, int8_t dy, int8_t wheel);

// CDC config channel
void usb_hid_set_cdc_line_handler(as_cdc_line_cb_t cb);  // one newline-framed line per call
void usb_hid_cdc_write(const char *data, unsigned len);  // response back on the CDC channel
```

The send functions return the TinyUSB queue result (false if the endpoint is busy or
the device is not mounted). The router task is expected to gate on `usb_hid_ready()`
and drop, not block, when USB is not the active sink.

All three report IDs share one HID IN endpoint, so only one report fits per host poll.
A caller submitting two reports back to back (gamepad then mouse in DUAL mode) will see
the second return false, because the first left the endpoint busy. The router handles
this by alternating gamepad and mouse across ticks (`as_modes/router.cpp`); any new
caller must serialize the same way rather than submit multiple reports per poll.

The header wraps the API in `namespace as { extern "C" { ... } }` under C++, so it is
callable from both the C implementation and the C++ router.

### TinyUSB callbacks implemented here

- `tud_hid_descriptor_report_cb` returns the combined report descriptor.
- `tud_hid_get_report_cb` answers INPUT probes with a zeroed report of the right
  length (gamepad 7, mouse/keyboard via the stock structs); other types return 0.
- `tud_hid_set_report_cb` is a stub; keyboard LED output reports would land here.

---

## Dependencies

From `idf_component.yml`: ESP-IDF >= 5.1 and `espressif/esp_tinyusb ^1`. Requires the
ESP32-S3 native USB OTG peripheral (HARDWARE.md: D- = GPIO19, D+ = GPIO20).

---

## Known gaps (Phase 0)

- **VERIFY** the `tinyusb_config_t` field names against the installed `esp_tinyusb ^1`
  at build time; the init code carries a note that the component API may have drifted.
- No keyboard report writer yet, though the keyboard descriptor is enumerated.
- The mouse descriptor is 8-bit relative (stock TinyUSB) and the gamepad has no hat.
  FIRMWARE.md now matches this. Richer shapes (int16 mouse deltas, a gamepad hat) are
  possible future enrichments, not current behaviour; this README is the wire-format
  source of truth.
- CDC config protocol is a logging stub (see above).
- Confirm Windows and the Xbox Adaptive Controller both enumerate the composite device
  cleanly and that runtime mode switches never trigger re-enumeration.

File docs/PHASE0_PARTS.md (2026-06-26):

# Phase 0 Parts List

Everything needed to run the Phase 0 bench items in [TODO.md](../TODO.md). This is a
validation shopping list, not the production BOM ([HARDWARE.md](HARDWARE.md) has that).
One order, roughly **$100-150** total, less if you already own the tools.

Where exact SKUs are given they are high-confidence; otherwise the Search term column is the
reliable way to find the part. Prices are mid-2026 ballpark.

> **Mechanism note:** the magnets, washers, ball, and PTFE below build the **ball-in-PTFE bench
> rig**, which characterises the dual-Hall sensing independent of the pivot. To bench the
> **primary pivot**, also print the Tetra II flexure from
> [`models/tetra2-flexure/`](../models/tetra2-flexure/) (PLA/PETG, no extra purchases) and measure
> its force on the gram gauge.

---

## 1. Electronics Bench

| Item | Qty | Source / search term | Est. | Unblocks |
|---|-----|---|---|---|
| ESP32-S3-DevKitC-1 (N8R2 or N16R8) | 2 | Amazon "ESP32-S3-DevKitC-1 N16R8", or Espressif official store (cheaper, slower) | $10-16 ea | All firmware spikes; 2nd board = dongle/AS-Link peer. **Skip if you have spares from ATOS work** |
| TMAG5273 breakout, Qwiic | 2 | SparkFun "Qwiic TMAG5273" (standard or mini) | ~$12 ea | Sensing bench: the primary sensor |
| MLX90393 breakout | 1 | Adafruit #4022 "Wide-Range 3-Axis Magnetometer" | ~$15 | The fallback/upgrade comparison datapoint |
| TLV493D breakout | 1 (optional) | Adafruit #4366 | ~$6 | Cheap third opinion if TMAG results look odd |
| Qwiic/STEMMA-QT cables | 4 | "Qwiic cable 100mm" + one breadboard-pigtail variant | ~$6 | Wiring without soldering |
| Bare TMAG5273A1 chips | 0 now | Digi-Key/Mouser, ~$1-2 ea | | Defer to pod PCB order; breakouts are the bench path |

Bench note: two identical TMAG5273 breakouts share a default I2C address. The scaffold
firmware probes for the sensor on I2C0 and runs single-sensor; the dual-sensor cross-check
bench will put sensor B on the S3's second I2C controller, so no address surgery is needed.

## 2. Magnetics and Mechanics Bench

Buy a small size spread of magnets; tuning signal swing and centering force against gap is
exactly what Phase 0 is for. All NdFeB N52.

| Item | Qty | Source / search term | Est. | Unblocks |
|---|-----|---|---|---|
| Diametric discs 4x2 mm | 10 | K&J Magnetics (filter: diametrically magnetized) or AliExpress "4x2mm N52 diametric" | ~$8 | Sense magnet, nominal size |
| Diametric discs 3x2 mm and 6x3 mm | 5 + 5 | same | ~$10 | Signal-swing spread |
| Ring magnets ~10 OD x 5 ID x 2 mm | 5 | "ring magnet 10x5x2 N52" | ~$6 | Centering force |
| Ring/disc alternates 8x3x2 ring, 6x2 disc | 5 + 5 | same suppliers | ~$6 | Force-range spread for the adjuster sweep |
| Discs 3x1 mm | 20 | "3x1mm N52" (usually 50-packs) | ~$6 | Topper quick-swap |
| Steel washers M3 | pack | hardware store / "M3 flat washer" | ~$3 | Centering armature |
| Bearing balls 4 mm, chrome steel | 50-pack | "4mm bearing balls G25" | ~$7 | Pivot |
| Bearing balls 4 mm, Si3N4 ceramic | 10 (optional) | "4mm silicon nitride ball" | ~$10 | Lighter pivot if mass budget gets tight |
| PTFE rod 12 mm dia x 100 mm | 1 | McMaster "PTFE rod 1/2 inch" or AliExpress | ~$8 | Machined-cup reference path |
| PTFE thread seal tape | 1 roll | any hardware store | ~$1 | Budget printed-seat path |

## 3. Measurement Tools

| Item | Qty | Source / search term | Est. | Unblocks |
|---|-----|---|---|---|
| Digital pocket scale, 0.01 g resolution | 1 | "0.01g pocket scale 100g" | ~$14 | Force measurement (with the pulley rig below) and the moving-mass budget |
| Dial tension gauge 0-50 g | 1 (alternative) | "dial tension gauge 50g" (keyboard switch testers use these) | ~$25 | Direct full-throw force reading; nicer but optional if you have the scale |
| Feeler gauge set | 1 | "feeler gauge set metric" | ~$8 | Setting the 1.5 mm sensor gap (a 1.5 mm drill shank also works) |
| Calibration masses | free | a US nickel is 5.000 g; a quarter is 5.670 g | $0.30 | Sanity-check the scale/gauge |

Force rig: a printed pulley + thread lets the 0.01 g scale read lateral stick force as added
weight. The rig STL goes in `models/` once the pod v0 prints; until then, a smooth dowel as a
thread guide works.

## 4. Consumables and Hardware

| Item | Qty | Source / search term | Est. |
|---|-----|---|---|
| Thin CA glue + accelerator | 1 | "thin CA glue kicker" | ~$10 |
| M2 + M3 brass/nylon screw assortment | 1 kit | "M2 M3 nylon screw assortment" | ~$8 |
| Carbon tube ~2.5 mm OD | 2-3 sticks | hobby/kite shop, "2.5mm carbon tube" | ~$6 |
| IPA 90%+ | 1 | pharmacy | ~$4 |
| Breadboard + jumpers | have? | any | ~$8 |

## 5. Defer to Stage B (do not order yet)

| Item | Why wait |
|---|---|
| LiPo + BQ24074 + MAX17048 breakouts | Battery option lands after the pod works on USB |
| MPXV7002DP sip/puff sensor | Stage B feature |
| DRV2605L (Adafruit #2305) + LRA | Stage B feature |
| 3.5 mm jacks, USB-C parts, bare sensors | Arrive with the PCB order |

---

## Order Strategy

- **Amazon/SparkFun/Adafruit now, AliExpress in parallel:** breakouts and tools from fast
  sources so the sensing bench starts this week; the magnet size-spread from AliExpress is
  fine because every magnet gets characterized by the bench anyway (lot-to-lot spread is data,
  not a problem, and the TMAG5273 itself is the gauss meter once it runs).
- **First bench session needs only:** one devkit + one TMAG5273 breakout + one Qwiic cable +
  any diametric magnet. Everything else can trickle in.
- Keep magnets in labeled bags away from the scale (they pull on the load cell through the
  case and corrupt readings).

## Checklist Mapping

| TODO Phase 0 item | Needs from this list |
|---|---|
| Sensing bench (swing/noise/bits) | Devkit, TMAG5273 x1-2, Qwiic, diametric magnets |
| TMAG5273 vs MLX90393 decision | + MLX90393 breakout |
| Z-press detection | same as sensing bench |
| Centering force 1-8 gf | Ring magnets, washers, scale or gauge |
| Pivot breakout force | Balls, PTFE, scale or gauge |
| Pod v0 print + moving mass | Carbon tube, magnets, balls, 0.01 g scale |
| TinyUSB / BLE / latency spikes | Devkits only (firmware ships with a simulation mode) |

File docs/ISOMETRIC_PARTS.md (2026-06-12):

# Isometric Joystick Parts List

> **Archived (V2):** the load-cell isometric approach was dropped in the V2 redesign; see
> [DESIGN_V2.md](DESIGN_V2.md) section 2 for the rationale (sustained-force fatigue, strain
> gauge drift, complexity). Kept for reference and for anyone who wants to build it anyway.

Specific parts and links for building an isometric (force-sensing, no-movement) joystick for Alpha Stick.

---

## Quick Summary

| Component | Budget Option | Premium Option |
|---|---|---|
| Load Cells (x4) | 50g micro load cells | 100g TAL221 (SparkFun) |
| ADC (x2) | HX711 modules | NAU7802 (Adafruit/SparkFun) |
| I2C Mux (if NAU7802) | PCA9548 module | Adafruit PCA9548 |
| **Total Cost** | **~$10-15** | **~$35-45** |

---

## Load Cells

### Budget: Generic 50g/100g Micro Load Cells

**AliExpress (~$1-2 each):**
- Search: "50g micro load cell" or "100g micro load cell strain gauge"
- Look for: 4-wire Wheatstone bridge, rated output ~0.6-1.0 mV/V
- Typical listings: ~$0.50-2 per cell

**Amazon (~$3-5 each):**
- [100g Micro Load Cell](https://www.amazon.com/dp/B0C9LDHFPK) — ~$8 for sensor + HX711
- [100g Load Sensor](https://www.amazon.com/dp/B07WSBC3W4) — ~$7
- Search "100g load cell arduino" for more options

### Premium: SparkFun TAL221 Mini Load Cell

**SparkFun / Amazon (~$5-7 each):**
- [SparkFun Mini Load Cell - 100g (TAL221)](https://www.amazon.com/dp/B07G5KVXT5) — ~$7
- Well-documented, consistent quality
- Rated capacity: 100g
- Output: 0.7 ± 0.15 mV/V

---

## ADC Modules

### Budget: HX711 (24-bit, ~$1-3 each)

**Amazon:**
- [DIYmall 2pcs HX711 Module](https://www.amazon.com/dp/B010FG9RXO) — ~$7 for 2
- [WWZMDiB 4pcs HX711](https://www.amazon.com/dp/B0BLND4VF6) — ~$9 for 4
- [5pcs HX711 + Jumper Wires Bundle](https://www.amazon.com/dp/B0CGZLQB8W) — ~$10

**AliExpress:**
- Search: "HX711 module" — ~$0.50-1 each

**Specs:**
- 24-bit resolution
- 10 or 80 SPS sample rate
- 2-wire interface (DT, SCK)
- Requires 2 modules for X and Y axes

### Premium: NAU7802 (24-bit, I2C, ~$7-10 each)

**Adafruit:**
- [Adafruit NAU7802 24-Bit ADC](https://www.adafruit.com/product/4538) — $6.95

**Amazon:**
- [Adafruit NAU7802 STEMMA QT](https://www.amazon.com/dp/B0CTGR5499) — ~$10
- [SparkFun Qwiic Scale NAU7802](https://www.amazon.com/dp/B082MPLRCS) — ~$16

**Specs:**
- 24-bit resolution
- Up to 320 SPS sample rate
- I2C interface (fixed address 0x2A)
- Lower noise than HX711
- Requires I2C multiplexer for 2 units

---

## I2C Multiplexer (Required for 2x NAU7802)

**Adafruit:**
- [Adafruit PCA9548 8-Channel I2C Mux](https://www.adafruit.com/product/5626) — $5.95

**Amazon:**
- [PCA9548A I2C Mux Module](https://www.amazon.com/s?k=PCA9548+I2C+multiplexer) — ~$5-8

**AliExpress:**
- Search: "PCA9548 module" — ~$1-2

---

## Recommended Kits

### Budget Build (~$12-18)

| Qty | Part | Source | Price |
|-----|---|---|---|
| 4 | 100g Micro Load Cell | AliExpress | $4 |
| 2 | HX711 Module | AliExpress | $2 |
| 1 | Jumper wires | — | $2 |
| | | **Total** | **~$8-12** |

Or from Amazon:
| Qty | Part | Source | Price |
|-----|---|---|---|
| 4 | 100g Load Cell + HX711 kit | Amazon | $15-20 |

### Premium Build (~$40-50)

| Qty | Part | Source | Price |
|-----|---|---|---|
| 4 | SparkFun TAL221 100g | SparkFun/Amazon | $28 |
| 2 | Adafruit NAU7802 | Adafruit | $14 |
| 1 | PCA9548 I2C Mux | Adafruit | $6 |
| 1 | STEMMA QT cables | Adafruit | $3 |
| | | **Total** | **~$51** |

---

## Wiring Quick Reference

### HX711 Setup (Budget)

```
ESP32-S3          HX711 #1 (X-axis)     Load Cells X+/X-
─────────         ────────────────      ────────────────
GPIO4 ──────────▶ DT                    
GPIO5 ──────────▶ SCK                   E+/E- ◀── power
3.3V  ──────────▶ VCC                   A+/A- ◀── signal
GND   ──────────▶ GND                   

ESP32-S3          HX711 #2 (Y-axis)     Load Cells Y+/Y-
─────────         ────────────────      ────────────────
GPIO6 ──────────▶ DT
GPIO7 ──────────▶ SCK
3.3V  ──────────▶ VCC
GND   ──────────▶ GND
```

### NAU7802 Setup (Premium)

```
ESP32-S3          PCA9548 Mux           NAU7802 #1 & #2
─────────         ───────────           ───────────────
GPIO8 (SDA) ────▶ SDA ─────────────────▶ SDA (both)
GPIO9 (SCL) ────▶ SCL ─────────────────▶ SCL (both)
3.3V  ──────────▶ VCC                   VCC
GND   ──────────▶ GND                   GND
                  CH0 ─────────────────▶ NAU7802 #1
                  CH1 ─────────────────▶ NAU7802 #2
```

---

## Software Libraries

### For HX711:
- **Arduino:** [bogde/HX711](https://github.com/bogde/HX711)
- Install via PlatformIO: `lib_deps = bogde/HX711`

### For NAU7802:
- **Arduino:** [Adafruit_NAU7802](https://github.com/adafruit/Adafruit_NAU7802)
- **SparkFun:** [SparkFun_Qwiic_Scale_NAU7802](https://github.com/sparkfun/SparkFun_Qwiic_Scale_NAU7802_Arduino_Library)
- Install via PlatformIO: `lib_deps = adafruit/Adafruit NAU7802 Library`

### For PCA9548 I2C Mux:
- **Adafruit:** [Adafruit_TCA9548A](https://github.com/adafruit/Adafruit_TCA9548A)
- Install via PlatformIO: `lib_deps = adafruit/Adafruit TCA9548A Library`

---

## Notes

- **50g vs 100g:** 50g cells are more sensitive but easier to overload. 100g recommended for durability.
- **Preload:** Load cells work best with slight preload. Design mounting to compress cells ~1-2g at rest.
- **Shielding:** Keep wires short and away from power lines to reduce noise.
- **Calibration:** Will need per-unit calibration in firmware. Store calibration values in ESP32 NVS.

---

## Next Steps

1. Order parts (budget or premium kit)
2. Design 3D printed mounting bracket
3. Wire up prototype on breadboard
4. Test sensitivity and noise levels
5. Iterate on mechanical design

See [HARDWARE.md](HARDWARE.md) for full isometric joystick documentation.

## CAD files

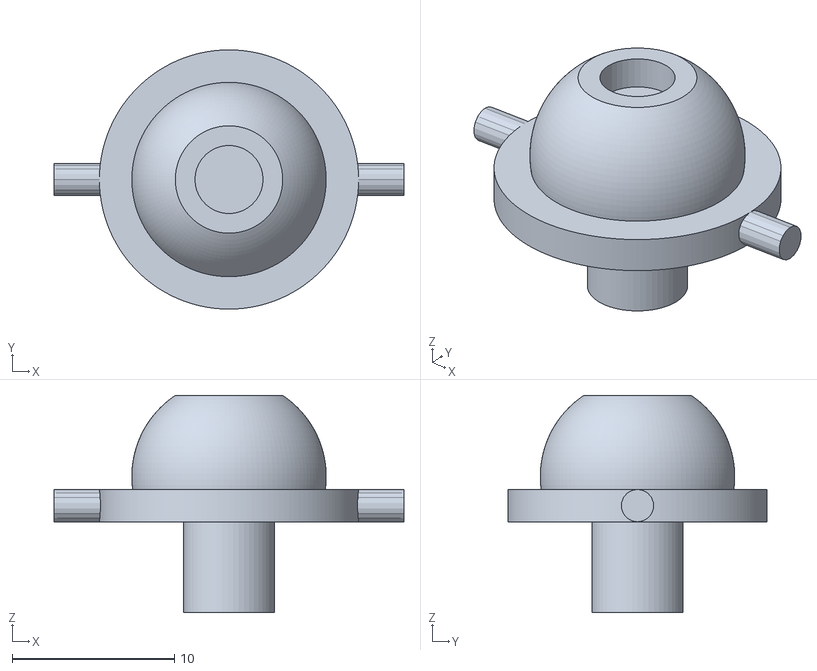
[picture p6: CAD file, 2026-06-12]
models/stl/pod/stick-hub-v0.stl
21.6 x 16.0 x 13.4

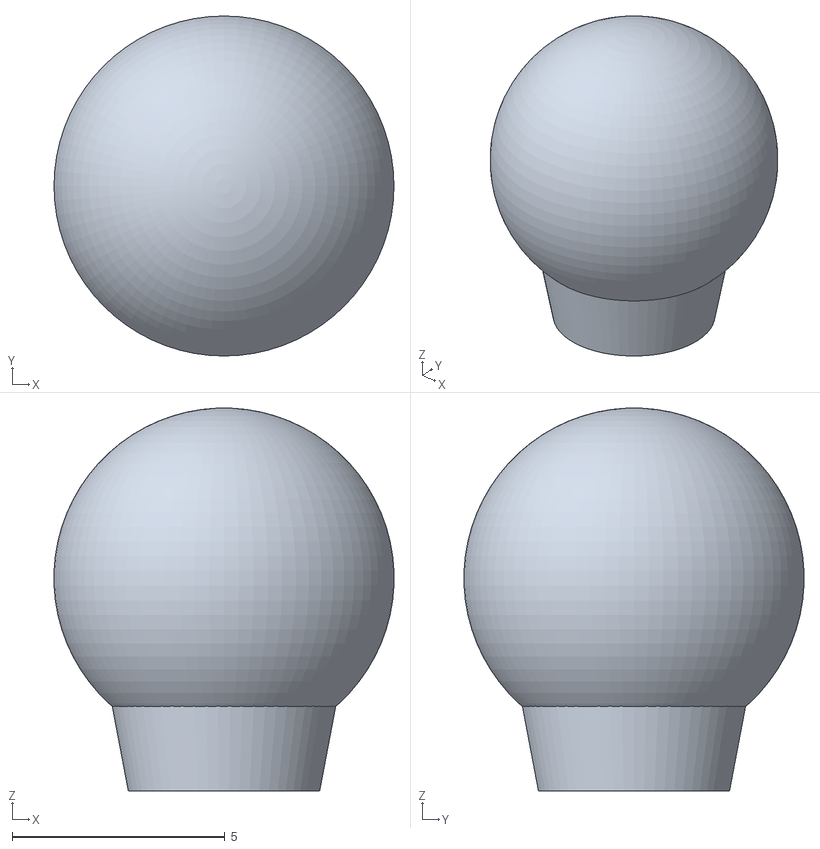
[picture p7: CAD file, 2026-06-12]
models/stl/toppers/topper-ball-v0.stl
7.99 x 7.99 x 9.00

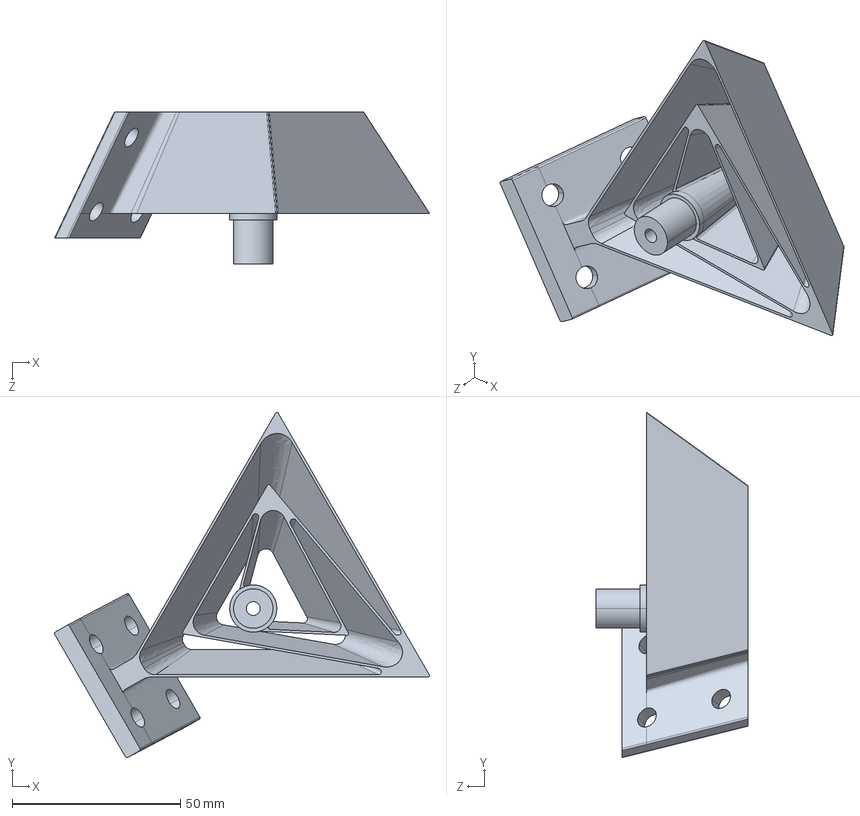
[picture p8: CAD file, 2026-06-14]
models/tetra2-flexure/Tetra2.STEP
111.3 x 102.5 x 45.0 mm

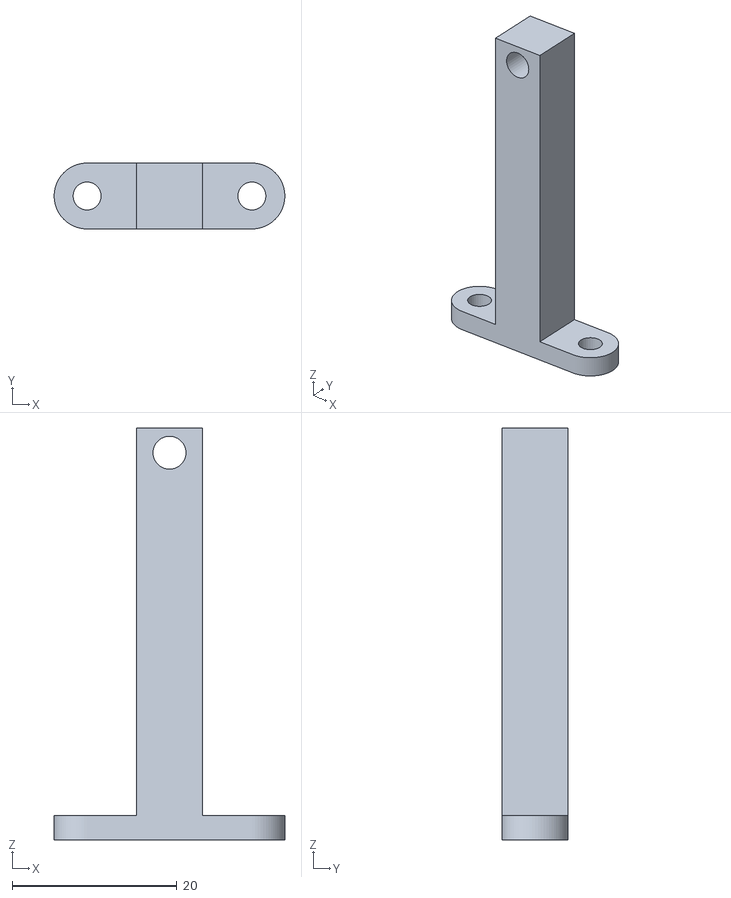
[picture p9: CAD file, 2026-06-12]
models/stl/pod/thread-guide-v0.stl
28.0 x 8.00 x 50.0

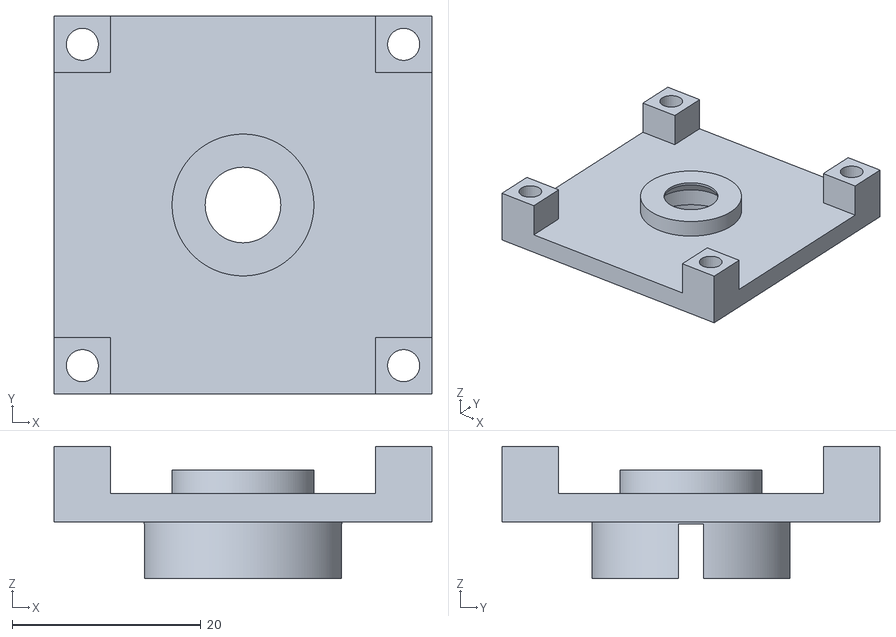
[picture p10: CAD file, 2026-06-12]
models/stl/pod/seat-housing-v0.stl
40.0 x 40.0 x 14.0

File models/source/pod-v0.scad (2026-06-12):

// Alpha Stick pod v0: Phase 0 bench rig (OpenSCAD source)
//
// Purpose: validate the V2 sensing + centering + pivot physics
// (docs/DESIGN_V2.md) using the parts on docs/PHASE0_PARTS.md, especially
// the SparkFun Qwiic TMAG5273 breakout (25.4 mm square). This is NOT the
// final 20 x 20 mm pod; it is the rig that produces the numbers the final
// pod will be sized from.
//
// v0 deviations from the production pod described in docs/HARDWARE.md:
//  - Pivot is a printed dome on the hub riding in a PTFE-tape-lined socket,
//    not a discrete steel ball (zero extra parts; the bench compares feel).
//  - Centering/preload comes from the sense magnet attracted to a ring
//    magnet or steel disc in the carrier below the breakout. The steel
//    washer armature returns with the real pod if the bench prefers it.
//  - No detent mechanism on the carrier; at gram-scale loads the printed
//    thread holds position by friction.
//
// Print guidance: docs/PRINTING.md. Hub and housing at 0.12 mm layers.
// Hub prints neck-down (dome up). Housing prints collar-down (socket up).
//
// Select what to render:
//   part = "hub" | "housing" | "base" | "carrier" | "topper" | "guide"
//        | "plate"    (all parts laid out for printing)
//        | "section"  (assembly cross-section for sanity checking)

part = "plate";

// -------------------------------------------------------------------------
// Parameters (mm). The bench exists to tune these; change and re-export.
// -------------------------------------------------------------------------

// sensing stack
pcb_size        = 25.4;   // SparkFun Qwiic breakout, square
pcb_thick       = 1.6;
sensor_top      = 0.9;    // IC top above PCB top face
sensor_gap      = 1.5;    // magnet bottom face to IC top (the design gap)

// sense magnet (N52 D4x2 diametric)
mag_d           = 4.0;
mag_h           = 2.0;
mag_proud       = 0.2;    // how far the magnet sticks out of the dome flat
fit_mag         = 0.2;    // diametral press/glue clearance for magnet pockets

// dome pivot
dome_r          = 6.0;
dome_flat_drop  = 5.0;    // flat cut distance below sphere center
seat_clear      = 0.2;    // socket radius oversize, leaves room for PTFE tape
seat_hole_r     = 4.0;    // socket center opening (magnet sightline)
seat_rim_r      = 5.5;    // outer radius of the spherical contact band

// hub
flange_r        = 8.0;
flange_t        = 2.0;
neck_r          = 2.8;
tube_d          = 2.6;    // 2.5 mm carbon tube + glue
tube_depth      = 8.0;
hub_top         = 16.0;   // hub overall height above base datum (z = 0)
pin_d           = 2.0;    // anti-yaw pins, radial at the flange
pin_reach       = 10.8;   // pin tip radius from axis

// housing
plate_z0        = 5.0;    // underside of the top plate (clears 3 mm Qwiic connectors)
plate_t         = 3.0;
plate_bore_r    = 7.0;    // clearance bore over the dome equator (r 6 + sway)
collar_ir       = 8.5;
collar_or       = 10.5;
collar_top      = 14.0;
slot_w          = 2.6;    // anti-yaw slot width (pin 2.0 + clearance)
slot_bottom     = 8.2;    // sets the tilt limit, ~7 deg with these numbers
housing_sq      = 40.0;   // post footprint, square
post_sq         = 6.0;

// bench base
base_sq         = 44.0;
base_t          = 6.0;
pocket_clear    = 0.4;    // breakout pocket oversize per side total
boss_d          = 18.0;
boss_len        = 10.0;   // threaded boss below the base
bore_plain_d    = 12.5;   // plain travel section above the thread
bore_plain_z    = 6.0;    // plain section depth below pocket floor
screw_pilot_d   = 2.8;    // M3 self-tap pilots (4.0 for heat-set inserts)

// adjuster carrier (M12 x 0.75 per docs/PRINTING.md)
thr_d           = 12.0;
thr_pitch       = 0.75;
thr_depth       = 0.45;
thr_clr         = 0.18;   // radial slop; tune per printer (PRINTING.md)
car_head_h      = 3.0;    // plain unthreaded top section
car_thread_len  = 11.0;   // grip stops on the boss tip just before the head
                          // can touch the breakout underside (0.4 mm margin)
car_pocket_d    = 10.4;   // ring magnet D10 or M5 washer stack, drop-in
car_pocket_h    = 3.0;
grip_d          = 18.0;
grip_h          = 3.0;

// topper and force-test guide
topper_ball_d   = 8.0;
guide_h         = 50.0;   // string guide notch near the 40 mm grip point

$fa = 2;
$fs = 0.35;

// -------------------------------------------------------------------------
// Derived stack (z = 0 is the bench base top face; PCB top sits flush at 0)
// -------------------------------------------------------------------------

mag_face_z   = sensor_top + sensor_gap;            // 2.4: magnet bottom face
dome_flat_z  = mag_face_z + mag_proud;             // 2.6: hub bottom flat
pivot_z      = dome_flat_z + dome_flat_drop;       // 7.6: sphere center
seat_r       = dome_r + seat_clear;                // 6.2: socket sphere
flange_z0    = plate_z0 + plate_t + 0.4;           // 8.4: flange floats over plate
pin_z        = flange_z0 + flange_t / 2;           // 9.4: pin centerline
echo("pivot center z", pivot_z);
echo("tilt limit deg",
     asin((pin_z - slot_bottom) / ((pin_reach + flange_r) / 2)));

module mirror2(v = [1, 0, 0]) { children(); mirror(v) children(); }

// -------------------------------------------------------------------------
// Printed thread: trapezoid tooth swept by a twisted extrude. Tooth angular
// width sets its axial thickness (width_deg / 360 * pitch).
// -------------------------------------------------------------------------

module thread_solid(d_major, pitch, length, depth, root_frac = 0.62,
                    crest_frac = 0.22, radial_off = 0) {
    r_maj = d_major / 2 + radial_off;
    r_min = r_maj - depth;
    root_deg  = 360 * root_frac;
    crest_deg = 360 * crest_frac;
    turns = length / pitch;
    linear_extrude(height = length, twist = -360 * turns, convexity = 10,
                   slices = ceil(turns * 24))
        union() {
            circle(r = r_min, $fn = 72);
            polygon([
                for (a = [-root_deg / 2 : root_deg / 24 : root_deg / 2])
                    [r_min * cos(a) * 0.999, r_min * sin(a) * 0.999],
                for (a = [crest_deg / 2 : -crest_deg / 12 : -crest_deg / 2])
                    [r_maj * cos(a), r_maj * sin(a)]
            ]);
        }
}

module thread_external(length) {
    thread_solid(thr_d, thr_pitch, length, thr_depth, radial_off = -thr_clr);
}

module thread_internal_cut(length) {
    // oversized solid to subtract from a boss
    thread_solid(thr_d, thr_pitch, length, thr_depth, radial_off = thr_clr);
}

// -------------------------------------------------------------------------
// stick-hub-v0: dome pivot, anti-yaw flange, tube neck, magnet pocket
// -------------------------------------------------------------------------

module hub() {
    difference() {
        union() {
            // dome: sphere trimmed to the working band
            intersection() {
                translate([0, 0, pivot_z]) sphere(r = dome_r);
                translate([0, 0, dome_flat_z])
                    cylinder(r = dome_r + 1, h = flange_z0 - dome_flat_z);
            }
            // flange + anti-yaw pins
            translate([0, 0, flange_z0]) cylinder(r = flange_r, h = flange_t);
            mirror2() translate([0, 0, pin_z]) rotate([0, 90, 0])
                cylinder(d = pin_d, h = pin_reach);
            // neck up to the tube socket
            translate([0, 0, flange_z0 + flange_t])
                cylinder(r = neck_r, h = hub_top - flange_z0 - flange_t);
        }
        // magnet pocket in the dome flat
        translate([0, 0, dome_flat_z - mag_proud - 0.01])
            cylinder(d = mag_d + fit_mag, h = mag_h + 0.01);
        // carbon tube bore
        translate([0, 0, hub_top - tube_depth])
            cylinder(d = tube_d, h = tube_depth + 0.01);
    }
}

// -------------------------------------------------------------------------
// seat-housing-v0: socket boss under a bridge plate, anti-yaw collar, posts
// -------------------------------------------------------------------------
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

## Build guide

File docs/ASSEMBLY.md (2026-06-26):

# Assembly Guide

Step-by-step instructions for assembling Alpha Stick **V2** (sensor pod + main board).

> **Draft status:** the V2 mechanism is in Phase 0 bench validation ([TODO.md](../TODO.md)).
> Steps and dimensions here match [DESIGN_V2.md](DESIGN_V2.md) and [HARDWARE.md](HARDWARE.md)
> and will be finalized with photos once the first pod articles are built.

> **Primary mechanism note:** this guide builds the **ball-in-PTFE-cup pod** — the alternative
> mechanism. The primary pivot is now the **Tetra II spherical flexure**: print it from
> [`models/tetra2-flexure/`](../models/tetra2-flexure/) and mount the stick + sense magnet to its
> moving platform (no ball, PTFE cup, ring magnet, washer, or force-adjuster carrier). The
> electronics, calibration, and main-board assembly below are identical for both pivots.

---

## Before You Begin

### Required Tools

| Tool | Purpose |
|---|---|
| Soldering iron (30-40W) | Connectors, jacks |
| Solder (60/40 or lead-free) | Electrical joints |
| Flush cutters / wire strippers | Wire prep |
| Phillips screwdriver (#1) | M2/M3 screws |
| Cyanoacrylate glue (thin) | **All press-fit magnets get glued** |
| Multimeter | Continuity checks |

### Strongly Recommended

| Tool | Purpose |
|---|---|
| Gram force gauge (0-50 g) | Verifying the 1-8 gf force range; cheap luggage-scale style works with a pulley |
| Feeler gauge or 1.5 mm drill shank | Setting the magnet-to-sensor gap |
| Digital scale (0.1 g) | Checking the 2.5 g moving-mass budget |
| Heat-set insert tip | M3 inserts in the base |

A US nickel is a calibrated 5.000 g reference mass; two quarters are ~11.3 g. Useful for
sanity-checking a gram gauge.

---

## Parts Checklist

### Sensor pod kit

- [ ] Pod PCB with 2x TMAG5273 (distinct I2C address variants) and JST-SH connector
- [ ] Sense magnet: N52 disc, D4 x 2 mm, **diametric**
- [ ] Ring magnet: N52, ~D10/D5 x 2 mm, axial
- [ ] Steel washer (M3, centering armature)
- [ ] 4 mm ball (steel or ceramic)
- [ ] PTFE cup (machined) or printed seat + PTFE tape
- [ ] Carbon stick tube (25/40/60 mm to taste)
- [ ] Printed: pod housing, adjuster carrier, stick hub, topper(s)
- [ ] Topper magnets: N52 D3 x 1 mm (one per topper + one in the hub)
- [ ] 6-pin JST-SH cable

### Main board kit

- [ ] Main PCB (assembled: ESP32-S3-MINI-1, USB-C, jacks, buttons, LEDs)
- [ ] Battery option: LiPo 503035 + slide switch (only if your board has the charger populated)
- [ ] Printed: base, top plate, button caps
- [ ] M3 x 8 mm screws (x4), M3 heat-set inserts (x4), M2 hardware for the pod (brass or nylon,
      **not steel**, near the sensors)

---

## Part A: Sensor Pod

The pod is the whole product; take your time here. Work on a clean bench, away from steel
shavings (magnets find them for you).

### A1. Mark the sense magnet axis

Diametric magnets have north on one *side*, not one face. Before installing:

1. Let the magnet snap sideways onto another magnet; the contact line marks the magnetic axis.
2. Mark that axis with a paint pen. It must end up aligned with the stick hub's index notch
   (the firmware calibration absorbs small errors, but starting aligned keeps the sweep clean).

### A2. Build the stick assembly

```
        carbon tube
            |
      +-----+-----+    stick hub (printed)
      | topper mag |   D3x1 in the top recess, glued
      |   tube     |   tube glued into the bore
      | washer     |   steel washer seated on the lower shoulder
      | sense mag  |   D4x2 diametric in the bottom recess, axis on the notch, glued
      +-----+-----+
            |
          (ball)       4 mm ball seats in the hub's bottom cup
```

1. Glue the carbon tube into the hub bore (CA, sparingly).
2. Seat the steel washer on its shoulder; a drop of CA.
3. Press the sense magnet into the bottom recess with the painted axis on the index notch; CA.
4. Press the topper magnet into the top recess; CA. **Check polarity against a topper before
   gluing** so toppers attract rather than repel.
5. Weigh the finished assembly: **target under 1.5 g** (leaves 1 g for a topper).

### A3. Build the pod housing

1. Press the PTFE cup (or printed seat lined with PTFE tape) into the housing center bore.
2. Glue the ring magnet into the adjuster carrier recess. Polarity: it must **attract** the
   steel washer (it will, either way, since the armature is steel; orientation only matters if
   you later swap the washer for a magnet).
3. Thread the carrier into the housing from below; stop at the middle detent.
4. Screw the pod PCB to the housing bosses with **brass or nylon M2** screws, sensors facing
   up, connector toward the cable channel.

### A4. Marry stick to pod and set the gap

1. Drop the ball into the PTFE cup, lower the stick hub onto it. The ring magnet should pull
   the assembly down into a seated, centered rest position.
2. Check the sense-magnet-to-sensor gap: **1.5 mm nominal** (1.0-2.5 mm usable). Adjust with
   the carrier; the printed stack is designed so the nominal detent lands near 1.5 mm.
3. Feel test: the stick should deflect with a fingertip brush, return crisply to center from
   every direction, and have zero perceptible grit. Grit means a contaminated cup: clean the
   ball and cup with IPA.
4. Force test (gauge or pulley + coins): full deflection in the 2-4 gf range at the middle
   detent, reaching roughly 1 gf backed out and 8 gf bottomed.

### A5. Connect and close

1. Plug the JST-SH cable, route through the channel, close the pod lid.
2. Snap a topper on. Verify it holds against an upside-down shake but releases with a pull.

---

## Part B: Main Board and Base

1. Install M3 heat-set inserts in the base (iron at 200-220 C, press gently, let cool).
2. Mount the main PCB on its standoffs (M3 x 5 mm).
3. Jacks and USB-C are board-mounted: align the base cutouts, no panel wiring needed.
4. Battery option: stick the LiPo in its bay with foam tape, route to the JST-PH, switch into
   its cutout. **Observe polarity; not all purchased LiPo pigtails match the board footprint.**
5. Seat the pod in its bay, connect the 6-pin cable to the main board.
6. Fit the top plate, start all four screws before tightening any, tighten evenly.
7. Press on button caps.

---

## Part C: Bring-Up Test

1. Connect USB. The device should enumerate as a composite HID gamepad/mouse/keyboard
   (Windows: check Device Manager, then "Set up USB game controllers").
2. Open a monitor for logs:

```powershell
cd C:\Users\Owen\dev\alpha-stick\firmware; idf.py -p COM5 monitor
```

3. Run the **guided calibration sweep** (hold both buttons at boot for config mode, connect to
   the `AlphaStick` AP, follow the calibration page): center hold, 8 compass points, full
   circle. See [CONFIGURATION.md](CONFIGURATION.md).
4. Verify in the web UI live view:
   - Full circle reaches the rim everywhere (no clipping, no flat spots)
   - Release from any direction settles within the center dot
   - Z-press registers at a light push, releases cleanly
5. Short each 3.5 mm jack tip-to-sleeve with a test cable: buttons fire.
6. If the dual-sensor health indicator shows disagreement, re-check magnet seating and gap.

---

## Magnet Handling and Safety

- **Glue every magnet.** Press-fits in printed plastic loosen with temperature cycles.
- Small magnets are an **ingestion hazard**; keep spares away from kids and pets.
- NdFeB is brittle: hand pressure only, never pliers or hammers.
- Keep magnets and tools with magnets away from the pod PCB during soldering; a magnetized
  iron tip near the sensors is a confusing afternoon.
- People with pacemakers/implants: follow the implant manufacturer's magnet distance guidance.
- LiPo: protected cells, correct polarity, no unattended charging.

---

## Troubleshooting

| Symptom | Likely cause | Fix |
|---|---|-----|
| Stick flops, weak return | Carrier backed out too far, washer missing/unseated | Set carrier to middle detent; verify washer |
| Stick sits off-center | Cup or seat printed off-axis; magnet recess off-center | Reprint housing; check hub concentricity |
| Gritty feel | Debris in PTFE cup | IPA-clean ball and cup; rebuild on a clean bench |
| Axes weak or nonlinear in live view | Sense magnet not diametric, or axis badly misaligned | Verify magnet type (A1 step); re-seat on the notch |
| `cal_valid` stays false | Sweep not run, or gap far off nominal | Set 1.5 mm gap, re-run calibration |
| Z-click never fires | Preload too high (carrier bottomed) | Back the carrier off a detent or two |
| Dual-sensor fault | One sensor address wrong, or board flex | Check both sensors enumerate on I2C; reflow |
| USB unknown device | Cable is charge-only | Use a known data cable |
| Random resets on WiFi | Brownout on weak USB port | Use a powered port/hub |

---

## Maintenance

- Wipe the stick and toppers with a dry cloth; IPA for the ball/cup if feel degrades.
- Re-run the calibration sweep after any pod disassembly or magnet change.
- Re-check the force setting if strength needs change day to day: that is what the carrier
  detents are for, no tools needed.
- Firmware updates: web UI upload or `idf.py flash`; see [FIRMWARE.md](FIRMWARE.md).

---

## Next Steps

- [CONFIGURATION.md](CONFIGURATION.md): calibration, profiles, modes
- [PRINTING.md](PRINTING.md): printed parts and settings
- [DESIGN_V2.md](DESIGN_V2.md): why the mechanism works

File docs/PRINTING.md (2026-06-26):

# 3D Printing Guide

Printed parts for Alpha Stick **V2**: the sensor pod mechanism, the bodies it drops into, and
toppers. Geometry is being finalized through Phase 0 bench work ([TODO.md](../TODO.md));
settings below are the targets the parts are designed around.

> **Primary pivot — the Tetra II flexure** prints as one piece from
> [`models/tetra2-flexure/`](../models/tetra2-flexure/Tetra2.STL): PLA works for a demonstrator,
> but **prefer PETG** for creep and fatigue life; ~0.7 mm blade walls (two slightly overlapping
> perimeters on a 0.4 mm nozzle); the Tetra2 mesh prints without supports. The pod-mechanism
> settings below are for the **alternative** ball-in-PTFE pod (housing, carrier, hub).

---

## Overview

V2 splits printing into three groups:

1. **Pod mechanism parts** (precision matters): pod housing, adjuster carrier, stick hub
2. **Bodies** (forgiving): desktop base, top plate, thumb puck, chin-boom hardware
3. **Toppers** (mass matters): ball, dish, lip bar, extensions

```
models/
+-- source/
|   +-- pod-v0.scad                   # parametric source for all pod v0 parts
+-- stl/
|   +-- pod/
|   |   +-- seat-housing-v0.stl       # PTFE-tape socket, anti-yaw slots, posts
|   |   +-- bench-base-v0.stl         # Qwiic breakout pocket, M12x0.75 boss
|   |   +-- adjuster-carrier-v0.stl   # ring magnet pocket, M12x0.75 thread
|   |   +-- stick-hub-v0.stl          # dome pivot, magnet pocket, tube bore
|   |   +-- thread-guide-v0.stl       # force-rig string guide
|   +-- bodies/                       # (production era, after Phase 0)
|   |   +-- base-desktop-v2.stl       # main PCB + pod bay + jack/USB cutouts
|   |   +-- top-plate-v2.stl
|   |   +-- thumb-puck-v2.stl         # 30 mm pod-only puck
|   |   +-- mount-adapter.stl         # 1/4-20 + AMPS
|   |   +-- button-cap-flat.stl
|   |   +-- button-cap-dome.stl
|   +-- toppers/
|       +-- topper-ball-8mm.stl
|       +-- topper-dish-14mm.stl
|       +-- topper-lip-bar.stl
|       +-- topper-ext-20.stl
|       +-- topper-ext-40.stl
+-- step/                             # for modification
+-- source/                           # FreeCAD/Fusion360
```

---

## Per-Part Settings (the table that matters)

| Part | Layer | Walls | Infill | Material | Notes |
|---|---|---|---|---|---|
| Pod housing | 0.12 mm | 4 | 40% | PETG/PCTG | Thread + cup bore need the fine layers |
| Adjuster carrier | 0.12 mm | 4 | 40% | PETG/PCTG | Test-fit thread; see thread tuning below |
| Stick hub | 0.12 mm | 100% solid | | PETG | Tiny part; solid for magnet retention |
| Desktop base / top plate | 0.2 mm | 3 | 20% | PLA/PETG | Standard settings |
| Thumb puck | 0.16 mm | 3 | 25% | PETG | |
| Mount adapter | 0.16 mm | 4 | 40% | PETG | Thread strength |
| Button caps | 0.12 mm | | 100% | PLA/PETG/TPU | |
| **Toppers** | 0.16 mm | 2 | 5% | PLA | **Hollow on purpose: each topper must weigh under 1 g** |

### The topper mass budget is real

The whole moving assembly has a 2.5 g budget ([DESIGN_V2.md](DESIGN_V2.md) section 3); heavy
toppers make the stick sag on tilted mounts. Print toppers light (2 walls, 5% infill), weigh
them, and write the mass on the bag. When designing custom toppers, hollow them.

### Thread tuning (housing + carrier)

The M12x0.75 adjuster thread is the only printed precision fit:

- Print both parts on the same printer with the same profile
- If the carrier binds: add 0.05-0.1 mm horizontal expansion compensation (slicer) and reprint
  the carrier only
- The detent spring finger is printed in place; if detents feel mushy at 0.2 mm layers, you
  skipped the 0.12 mm requirement
- A dry PTFE-based lubricant (never grease: it migrates to the pivot) is acceptable on the
  thread

### Pivot seat note

The reference pivot is a machined PTFE cup pressed into the housing. The budget path is a
printed seat in **PCTG/PETG lined with PTFE tape**: print the seat bore 0.2 mm oversize to
leave room for the tape layer. PLA works but creeps under the preload over months; prefer
PETG-class materials anywhere the magnets load the plastic.

---

## Materials

| Material | Use in V2 | Notes |
|---|---|---|
| PLA | Bodies, toppers | Easy, fine for everything that is not preloaded |
| PETG / PCTG | Pod mechanism, anything magnet-loaded, travel builds | Creep resistance is why |
| TPU | Button caps, grippy topper sleeves | Optional |
| ABS/ASA | Not needed | Skip unless the unit lives in a hot car |

**Mouthpiece caution:** FDM prints are porous and hard to sanitize. For mouth-operated use,
the printed part should hold a **commercial food-safe mouthpiece** (CamelBak-style bite valve
or QuadStick-compatible mouthpiece) rather than being the mouthpiece itself.

---

## General Print Settings

| Setting | Value | Notes |
|---|---|---|
| Layer height | 0.2 mm bodies, 0.12 mm pod parts | Per-part table above wins |
| Walls | 3 (4 for threads) | |
| Top/bottom | 4 | |
| Speed | 50 mm/s, slower for pod parts | |
| Supports | None | Parts are designed support-free |
| Adhesion | Brim optional | |

Minimum printer: 150 x 150 x 100 mm (Ender 3 class). The largest part (base) is ~120 x 80 mm.

---

## Print Orientation

```
Pod housing: cup bore UP          Carrier: thread UP, magnet recess down
   +---------+                        +-----+
   | o cup o |                        |#####|  <- thread
   |  bosses |                        +--+--+
   +---------+                        |     |
   bed                                bed

Stick hub: neck DOWN (dome up,    Base: flat, bottom down
   smooth pivot surface on top)   Top plate: top face DOWN (smooth)
                                  Toppers: stem down, no supports
Pod v0 STLs export pre-flipped to their print orientation
(see models/README.md), so slice them as they load.
```

Orientation matters most on the hub and housing: the magnet recesses and cup bore should be
printed as horizontal circles (around the Z axis) so they come out round.

---

## Bodies: One Pod, Many Builds

| Body | Status | Purpose |
|---|---|---|
| Desktop base | V2 default | Main PCB + pod, palm-friendly, jack/USB access |
| Thumb puck | V2 | Pod-only 30 mm puck on a cable, for tray mounting |
| Chin boom pod | Planned | Pod + cable on a gooseneck/boom clamp |
| Mouth-stick frame | Planned | Vertical frame, sip/puff tube routing, bite-valve holder |
| Dual-stick base | Backlog | Two pods, one main board |

All bodies accept the same pod and the same 6-pin cable; print the body your mounting
situation needs.

---

## Mounting

- Base and puck carry the **AMPS hole pattern** plus a **1/4-20 brass insert**: RAM mounts,
  Magic Arms, tripods, wheelchair tray clamps
- Set the insert with a soldering iron at ~220 C, flush or slightly proud, let cool fully
  before loading

---

## Hardware for Printed Parts

| Item | Qty | Use |
|---|-----|-----|
| M3 x 8 mm + heat-set inserts | 4 | Base to top plate |
| M3 x 5 mm | 2-4 | PCB standoffs |
| M2 brass or nylon screws | 2-3 | Pod PCB (**non-magnetic, near sensors**) |
| 1/4-20 brass insert | 1 | Mounting |

---

## Troubleshooting

| Problem | Cause | Fix |
|---|---|-----|
| Carrier thread binds | Over-extrusion / no compensation | Horizontal expansion -0.05 to -0.1 mm, reprint carrier |
| Detents feel mushy | Layer height too coarse | 0.12 mm on housing + carrier |
| Stick sits off-center | Cup bore or magnet recess out of round | Reprint with part oriented per the diagrams; check belts |
| Magnets fall out | Press-fit only | Always glue (thin CA) |
| Warping | Adhesion/drafts | Clean bed, brim, slow first layer |
| Stringing on PETG | Temp/retraction | Reduce 5-10 C, dry filament |
| Parts don't fit | Elephant foot | First-layer squish down, or chamfered reprint |

---

## Print Time Estimates

| Part | Time | Filament |
|---|---|---|
| Pod set (housing + carrier + hub) | ~2 h | ~15 g |
| Desktop base | 4-5 h | ~50 g |
| Top plate | 2-3 h | ~30 g |
| Topper set | ~45 min | ~6 g |
| Mount adapter | 30 min | ~5 g |
| **Full desktop build** | **~9 h** | **~105 g** |

---

## Community Designs

Custom toppers and bodies are the easiest, highest-value contributions:

- **GitHub:** PRs to `models/community/` (include the printed mass of toppers)
- **Printables/Thingiverse:** tag `AlphaStick`

---

## Next Steps

1. Print a pod set at 0.12 mm and the desktop base at 0.2 mm
2. Assemble per [ASSEMBLY.md](ASSEMBLY.md)
3. Calibrate per [CONFIGURATION.md](CONFIGURATION.md)

See [HARDWARE.md](HARDWARE.md) for the electronics that go inside.

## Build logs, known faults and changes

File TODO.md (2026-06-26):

# Alpha Stick TODO

Task tracking for the Alpha Stick project.

---

## Phase 0: V2 Redesign Validation (Current)

First-principles redesign baseline: see [docs/DESIGN_V2.md](docs/DESIGN_V2.md). Bench-validate the core physics before any enclosure or PCB work.

### Order
- [ ] **Order Phase 0 bench parts** per [docs/PHASE0_PARTS.md](docs/PHASE0_PARTS.md)

### Sensing Bench
- [ ] **Breadboard dual TMAG5273 + tilting magnet** and measure field swing, noise, effective bits at 1 kHz
- [ ] **Decide TMAG5273 vs MLX90393** from bench data (need >=8 effective bits/axis)
- [ ] **Verify Z-press detection** with clean hysteresis at <5 gf (free gap-change on the ball pod; on the flexure, axial is stiff — Z-click via a compliant mount or a switch is a follow-up)

### Mechanics Bench
- [x] **Model pod v0 printables** — parametric OpenSCAD source + STLs ([models/](models/))
- [ ] **Print the Tetra II flexure** ([models/tetra2-flexure/](models/tetra2-flexure/)) and **measure its full-deflection force** on the gram gauge (PLA first, then PETG); iterate blade thickness/scale toward the ~3 gf nominal — this is the **primary** pivot
- [ ] **Measure flexure breakout** (expect ~0, no sliding) and return-to-center repeatability; start a **creep/fatigue soak** (the primary risk)
- [ ] **Weigh the flexure moving assembly** (platform + inner blades + stick + magnet) and re-derive the gravity-bias budget
- [ ] *Alternative pod:* prototype magnetic centering + threaded force adjuster (confirm 1-8 gf), measure ball-in-PTFE breakout (<0.5 gf), print sensor pod v0 — the fallback if flexure creep wins

### Firmware Spikes
- [ ] **ESP-IDF TinyUSB composite spike** (gamepad + mouse + CDC) at 1 kHz on S3 devkit; verify DUAL-mode dual-report streaming and cross-task `tud_` call safety under sustained load
- [ ] **BLE HID multi-report spike** (gamepad + mouse in one HID service)
- [ ] **Measure wired stimulus-to-report latency** (<5 ms target)
- [x] **USB CDC JSON config protocol + native host tools** (get/set/info/save/defaults/reboot; GUI configurator + CLI flasher in [tools/](tools/))
- [ ] **Jack + sip/puff input subsystem and button/macro runtime engine** (unblocks the button maps and macros the configurator already authors)

### Integration Groundwork
- [ ] **Draft AS-Link frame header** (shared .h) and an ATOS gateway module skeleton
- [ ] **Test a generic HID stick against the XAC USB port** to de-risk the Xbox path
- [x] **Rewrite HARDWARE.md and FIRMWARE.md** to match the V2 baseline

---

## Phase 1: Foundation (largely superseded by Phase 0, see docs/DESIGN_V2.md)

### Hardware Design
- [ ] **Research joystick modules** — Compare analog vs hall-effect options
- [ ] **Select ESP32 variant** — ESP32-S3 vs ESP32-C3 for USB HID support
- [ ] **Define 3.5mm jack pinout** — Standard for external switch compatibility
- [ ] **Create initial schematic** — Basic connections for MVP
- [ ] **Identify mounting options** — RAM mount, Magic Arm, flat surface

### 3D Modeling
- [ ] **Design base enclosure** — Fits ESP32 + joystick + 2 buttons
- [ ] **Design top cover** — Joystick access, ergonomic palm rest
- [ ] **Create mounting adapter** — Compatible with standard camera mounts
- [ ] **Prototype in CAD** — FreeCAD or Fusion360

### Firmware
- [x] **Set up ESP-IDF project** — ESP32-S3 target (`firmware/` scaffold with simulation mode)
- [ ] **Implement USB HID gamepad** — Basic joystick + buttons
- [ ] **Read analog joystick input** — ADC sampling with smoothing
- [ ] **Add basic deadzone** — Configurable center deadzone

### Documentation
- [x] Create README.md with project overview
- [x] Create TODO.md for task tracking
- [ ] Create LLM_ONBOARDING.md for AI assistants
- [ ] Draft HARDWARE.md with component selection rationale
- [ ] Draft FIRMWARE.md with architecture overview
- [ ] Draft PRINTING.md with recommended settings

---

## Phase 2: Prototype

### Hardware
- [ ] **Build breadboard prototype** — Validate component choices
- [ ] **Test joystick modules** — Compare feel and precision
- [ ] **Test 3.5mm switch input** — Verify external switch compatibility
- [ ] **Design PCB v0.1** — Single-sided, easy to solder
- [ ] **Order PCB prototype** — JLCPCB or similar

### 3D Printing
- [ ] **Print first enclosure** — Test fit, ergonomics
- [ ] **Iterate on design** — Refine based on testing
- [ ] **Add ventilation** — Prevent overheating
- [ ] **Design button caps** — Different shapes for different needs

### Firmware
- [ ] **Implement sensitivity curves** — Linear, exponential, custom
- [ ] **Add button debouncing** — Configurable timing
- [ ] **Create web configuration portal** — ESP32 soft AP mode
- [ ] **Store settings in NVS** — Persistent configuration
- [ ] **Implement profile system** — Save/load multiple configs

### Testing
- [ ] **Test with Xbox Adaptive Controller** — 3.5mm jack compatibility
- [ ] **Test with PC games** — USB HID recognition
- [ ] **Test with Project Nimbus** — Integration verification
- [ ] **Gather user feedback** — Ergonomics, usability

---

## Phase 3: Refinement

### Bluetooth Support
- [ ] **Implement BLE HID gamepad** — Wireless operation
- [ ] **Add pairing mode** — Button combo to enter pairing
- [ ] **Test multi-device pairing** — Switch between devices
- [ ] **Optimize power consumption** — For battery operation

### OTA Updates
- [ ] **Implement OTA update system** — esp_https_ota with A/B rollback
- [ ] **Create update server/process** — GitHub releases integration
- [ ] **Add rollback mechanism** — Recover from bad updates

### Advanced Features
- [ ] **Sip/puff input** — Pressure sensor integration
- [ ] **Tremor filtering** — Configurable smoothing algorithm
- [ ] **OLED status display** — Show profile, battery, connection
- [ ] **LED indicators** — Status, profile, low battery
- [ ] **Battery monitoring** — Voltage sensing, low battery warning

### Alternative Input Modes
- [ ] **Mouse mode** — Joystick controls cursor
- [ ] **Keyboard mode** — Joystick sends arrow keys
- [ ] **Xbox Adaptive mode** — Optimized for XAC compatibility
- [ ] **Flight sim mode** — Multi-axis with throttle

---

## Phase 4: Release

### Documentation
- [ ] **Complete assembly guide** — Step-by-step with photos
- [ ] **Create video tutorial** — Build walkthrough
- [ ] **Write troubleshooting guide** — Common issues and fixes
- [ ] **Translate to other languages** — Community contributions

### Community
- [ ] **Create Discord server** — Community hub
- [ ] **Build profile library** — Shared configurations
- [ ] **Publish to Makers Making Change** — Reach accessibility community
- [ ] **Submit to Hackaday.io** — Visibility in maker community

### Polish
- [ ] **Finalize PCB design** — Production-ready
- [ ] **Create BOM with links** — Easy ordering
- [ ] **Test across platforms** — PC, Xbox, PlayStation, Switch
- [ ] **Tag v1.0 release** — Stable, documented, tested

---

## Backlog / Future Ideas

- [ ] Mouth-operated variant (inspired by QuadStick)
- [ ] Foot pedal design
- [ ] Eye-tracking integration
- [ ] Voice command integration
- [ ] Haptic feedback (vibration motor)
- [ ] Modular button plates (hot-swap different layouts)
- [ ] Wireless charging support
- [ ] Integration with Steam Input
- [ ] macOS/Linux configuration app
- [ ] Mobile app for configuration

---

## Completed

- [x] Set up GitHub repository
- [x] Add MIT license
- [x] Create Constellation integration guide

---

*Last updated: June 2026*

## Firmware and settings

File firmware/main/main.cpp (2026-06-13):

#include <cstdlib>
#include <cstring>

#include "esp_log.h"
#include "esp_system.h"
#include "freertos/FreeRTOS.h"
#include "freertos/task.h"
#include "nvs_flash.h"
#include "sdkconfig.h"

#include "as_config/config.h"
#include "as_config/config_protocol.h"
#include "as_hid_ble/ble_hid.h"
#include "as_hid_usb/usb_hid.h"
#include "as_modes/router.h"
#include "as_sensing/mailbox.h"
#include "as_sensing/sensing.h"
#include "as_web/web.h"

static const char *TAG = "main";

static as::Mailbox<as::StickSample> s_mailbox;

// Bridge USB CDC config lines to the JSON protocol. Runs in the TinyUSB task
// context; the response is written back on the same CDC channel.
extern "C" void as_cdc_on_line(const char *line)
{
    char *resp = as::config_protocol_handle_line(line);
    if (resp) {
        as::usb_hid_cdc_write(resp, (unsigned)strlen(resp));
        as::usb_hid_cdc_write("\n", 1);
        free(resp);
    }
    if (as::config_protocol_take_reboot()) {
        vTaskDelay(pdMS_TO_TICKS(100));  // let the ack drain first
        esp_restart();
    }
}

extern "C" void app_main(void)
{
#if CONFIG_AS_BUILD_PROFILE_DRIVE
    ESP_LOGW(TAG, "Alpha Stick V2, DRIVE build profile");
#else
    ESP_LOGI(TAG, "Alpha Stick V2, gaming build profile");
#endif
#if CONFIG_AS_ROLE_DONGLE
    ESP_LOGW(TAG, "role: DONGLE (AS-Link bridge), not implemented yet");
#endif

    esp_err_t err = nvs_flash_init();
    if (err == ESP_ERR_NVS_NO_FREE_PAGES || err == ESP_ERR_NVS_NEW_VERSION_FOUND) {
        ESP_ERROR_CHECK(nvs_flash_erase());
        err = nvs_flash_init();
    }
    ESP_ERROR_CHECK(err);

    as::config_init();
    as::usb_hid_init();
    as::usb_hid_set_cdc_line_handler(as_cdc_on_line);
    as::ble_hid_init();
    as::web_init();

    as::sensing_start(s_mailbox);
    as::router_start(s_mailbox);

    ESP_LOGI(TAG, "up: profile '%s', mode %d",
             as::config_profile().name, (int)as::config_profile().mode);
}

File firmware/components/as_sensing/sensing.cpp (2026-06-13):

#include "as_sensing/sensing.h"

#include <cmath>

#include "driver/i2c_master.h"
#include "esp_log.h"
#include "esp_timer.h"
#include "freertos/FreeRTOS.h"
#include "freertos/task.h"
#include "sdkconfig.h"

#include "as_config/config.h"
#include "as_pipeline/pipeline.h"
#include "as_sensing/tmag5273.h"

namespace as {

namespace {

const char *TAG = "sensing";

constexpr gpio_num_t kSda = GPIO_NUM_8;
constexpr gpio_num_t kScl = GPIO_NUM_9;
constexpr float kFullScaleRad = 5.0f * (float)M_PI / 180.0f;  // +/-5 deg throw

struct Ctx {
    Mailbox<StickSample> *mailbox;
    Tmag5273 sensor;
    bool live = false;
};

// Direction-based tilt estimate: angle of the field vector against the sensor
// normal, which is what makes the measurement gap- and temperature-tolerant
// (docs/DESIGN_V2.md sec 4). Placeholder until the calibration map exists:
// assumes the rest field is along +Z and axes are aligned with the PCB.
void field_to_norm(float bx, float by, float bz, float &nx, float &ny, float &nz,
                   float baseline_mag)
{
    const float az = std::fabs(bz) > 1e-3f ? bz : 1e-3f;
    nx = std::atan2(bx, az) / kFullScaleRad;
    ny = std::atan2(by, az) / kFullScaleRad;

    // Z press: |B| rises as the gap closes. Gain 8 maps a ~12% magnitude
    // increase to full press; tune on the bench.
    const float mag = std::sqrt(bx * bx + by * by + bz * bz);
    nz = baseline_mag > 1e-3f ? (mag / baseline_mag - 1.0f) * 8.0f : 0.0f;
}

void sensing_task(void *arg)
{
    Ctx *ctx = static_cast<Ctx *>(arg);
    Pipeline pipeline;
    pipeline.set_profile(config_profile());
    uint32_t cfg_gen = config_generation();

    float baseline_mag = 0.0f;
    if (ctx->live) {
        // Capture the rest-field magnitude as the Z-press baseline.
        float acc = 0.0f;
        int n = 0;
        for (int i = 0; i < 200; ++i) {
            float bx, by, bz;
            if (ctx->sensor.read_mT(bx, by, bz) == ESP_OK) {
                acc += std::sqrt(bx * bx + by * by + bz * bz);
                ++n;
            }
            vTaskDelay(1);
        }
        baseline_mag = n > 0 ? acc / n : 0.0f;
        ESP_LOGI(TAG, "LIVE: TMAG5273 at 0x%02X, |B| baseline %.2f mT",
                 ctx->sensor.address(), baseline_mag);
    } else {
        ESP_LOGW(TAG, "SIMULATION: no sensor found, synthesizing input");
    }

    TickType_t wake = xTaskGetTickCount();
    uint32_t prev_us = (uint32_t)esp_timer_get_time();
    for (;;) {
        vTaskDelayUntil(&wake, 1);  // 1 ms with CONFIG_FREERTOS_HZ=1000

        // Pick up config edits pushed over USB CDC without a reboot.
        const uint32_t gen = config_generation();
        if (gen != cfg_gen) {
            pipeline.set_profile(config_profile());
            cfg_gen = gen;
        }

        const uint32_t now_us = (uint32_t)esp_timer_get_time();
        const float dt_s = (now_us - prev_us) * 1e-6f;
        prev_us = now_us;

        float nx, ny, nz;
        bool cal_valid;
        if (ctx->live) {
            float bx, by, bz;
            if (ctx->sensor.read_mT(bx, by, bz) != ESP_OK) {
                continue;  // missed sample; watchdog wiring is a TODO
            }
            field_to_norm(bx, by, bz, nx, ny, nz, baseline_mag);
            cal_valid = false;  // true once the real calibration map lands
        } else {
            // Slow circle at 0.2 Hz, 80% deflection, Z pulse every 3 s.
            const float t = now_us * 1e-6f;
            const float w = 2.0f * (float)M_PI * 0.2f;
            nx = 0.8f * std::sin(w * t);
            ny = 0.8f * std::cos(w * t);
            nz = (std::fmod(t, 3.0f) < 0.2f) ? 1.0f : 0.0f;
            cal_valid = true;
        }

        const Pipeline::Out o = pipeline.process(nx, ny, nz, dt_s);

        StickSample s;
        s.x = o.x;
        s.y = o.y;
        s.z = o.z;
        s.t_us = now_us;
        s.cal_valid = cal_valid;
        s.dual_ok = false;  // sensor B on I2C1 + cross-check is a Phase 0 task
        s.tare_stable = true;
        s.simulated = !ctx->live;
        ctx->mailbox->write(s);
    }
}

}  // namespace

void sensing_start(Mailbox<StickSample> &mailbox)
{
    static Ctx ctx;
    ctx.mailbox = &mailbox;

    i2c_master_bus_config_t bus_cfg = {};
    bus_cfg.i2c_port = I2C_NUM_0;
    bus_cfg.sda_io_num = kSda;
    bus_cfg.scl_io_num = kScl;
    bus_cfg.clk_source = I2C_CLK_SRC_DEFAULT;
    bus_cfg.glitch_ignore_cnt = 7;
    bus_cfg.flags.enable_internal_pullup = true;

    i2c_master_bus_handle_t bus = nullptr;
    if (i2c_new_master_bus(&bus_cfg, &bus) == ESP_OK &&
        ctx.sensor.probe(bus) == ESP_OK &&
        ctx.sensor.start_continuous() == ESP_OK) {
        ctx.live = true;
    }

#if !CONFIG_AS_SIMULATE_WHEN_NO_SENSOR
    if (!ctx.live) {
        ESP_LOGE(TAG, "no sensor and simulation disabled; sensing not started");
        return;
    }
#endif

    xTaskCreatePinnedToCore(sensing_task, "as_sensing", 4096, &ctx,
                            configMAX_PRIORITIES - 3, nullptr, 1);
}

}  // namespace as

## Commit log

2026-01-21 Add project documentation and configuration files
    Added .gitignore with build artifacts, IDE files, Python cache, and AI scratch space exclusions. Created comprehensive integration guide for Constellation meta-repository tracking with PowerShell com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
2026-01-22 Add Joypad OS reference architecture documentation
    Added Joypad OS to related projects list as reference architecture for universal controller firmware. Documented architectural similarities between Alpha Stick and Joypad OS including input processin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
2026-01-31 Add isometric joystick hardware documentation
    Added comprehensive documentation for isometric force-sensing joystick as alternative to standard analog stick. Includes component BOM with micro load cells, NAU7802/HX711 ADCs, and I2C multiplexer. 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
2026-06-12 docs: rebase project on V2 first-principles design
    - add docs/DESIGN_V2.md: contactless dual-Hall sensing, passive magnetic
    centering adjustable 1-8 gf, ball-in-PTFE pivot, ~2 mm throw, sensor pod
    architecture, staged roadmap (Glide/Bridge/Field), AS-Link protocol for
    ATOS drive-input integration
    - rewrite HARDWARE.md as the V2 build reference (pod, main board, pins,
    wiring, BOM); drops gimbal-pot and load-cell isometric approaches
    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
2026-06-12 docs: align assembly, configuration, and printing guides with V2
    - rewrite ASSEMBLY.md for the sensor pod build (magnet prep, pivot,
    gap/force targets, bring-up test, magnet safety)
    - rewrite CONFIGURATION.md for V2 (calibration sweep, mount tare, modes,
    radial deadzone, 1-euro filter presets, dwell click, sip/puff, BLE
    bonds, profile JSON schema, corrected XAC-via-USB guidance)
    - rewrite PRINTING.md for V2 parts (pod mechanism settings, thread
    tuning, topper mass budget, pod bodies, food-safe mouthpiece note)
    - add archived banner to ISOMETRIC_PARTS.md
    - sweep remaining Arduino/PlatformIO references from README,
    CONTRIBUTING, LLM_ONBOARDING, TODO
2026-06-12 feat: add Phase 0 parts list and ESP-IDF firmware scaffold
    - docs/PHASE0_PARTS.md: bench shopping list (~$100-150) mapped to the
    Phase 0 TODO items, with order strategy and a defer-to-Stage-B table
    - firmware/: ESP-IDF 5.x project implementing the docs/FIRMWARE.md
    architecture: 1 kHz sensing task with seqlock mailbox, TMAG5273 driver
    (register values flagged VERIFY), processing pipeline (radial deadzone,
    expo curve, 1-euro filter), router task with gamepad + mouse paths and
    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
    [partitions.csv]
2026-06-12 docs: add development workflow guide and bench log
    - WORKFLOW.md: source-of-truth map, the Phase 0 bench loop, CAD and
    firmware loop commands, change-propagation table, tracking and git
    conventions, worked example
    - BENCH_LOG.md: append-only measurement log with entry template
    - link both from README structure and LLM_ONBOARDING key files
2026-06-12 docs: add executive summary, whitepaper, and community infrastructure
    - EXECUTIVE_SUMMARY.md: one-page pitch (problem, solution, novelty,
    status, roadmap, ATOS connection)
    - WHITEPAPER.md: self-contained technical narrative with explicit
    estimates-vs-measurements candor and falsifiable validation plan
    - community readiness: refreshed CONTRIBUTING (where-to-start, V2 model
    and code conventions), Contributor Covenant 2.1, issue forms (bug,
    feature, build/bench report, accessibility feedback), PR template
    - CI: firmware build (ESP-IDF v5.3, esp32s3) and OpenSCAD render checks,
    path-filtered; first green firmware build flagged as a good first
    contribution
    - README: Phase 0 status, re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
2026-06-12 feat: add pod v0 bench rig CAD (parametric source + STLs)
    - models/source/pod-v0.scad: all six parts in one parametric file with
    the gap-stack arithmetic derived and echoed (pivot z, tilt limit);
    printed M12x0.75 thread module with tunable clearance
    - parts: stick hub (dome pivot, magnet pocket, anti-yaw pins), seat
    housing (PTFE-tape socket, collar slots), bench base (Qwiic breakout
    pocket, threaded boss), adjuster carrier, ball topper, force-rig
    string guide
    - STLs exported pre-flipped to print orientation; all verified as
    2-volume manifold solids; section and plate preview PNGs included
    - models/README.md: mechanism explanation, v0 deviations from the
    production pod, print n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
    [pod-v0.scad, seat-housing-v0.stl, stick-hub-v0.stl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]
2026-06-12 chore: re-export STLs as binary (4x smaller, same geometry)
    [seat-housing-v0.stl, stick-hub-v0.stl, thread-guide-v0.stl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]
2026-06-13 fix(usb-hid): stop DUAL mode dropping mouse reports; harden HID/CDC
    The three report IDs share one HID IN endpoint, so the gamepad report
    submitted first left the endpoint busy and the mouse report was dropped
    almost every tick in DUAL mode. Alternate gamepad and mouse across ticks in
    the router so each streams at ~500 Hz, integrating mouse motion every tick so
    a skipped tick is carried, not lost.
    Also harden the USB stack: advertise 500 mA to cover WiFi config-mode peaks,
    drain the CDC RX FIFO fully instead of one buf, answer GET_REPORT input probes
    with a zeroed report instead of stalling, and document the cross-task tud_
    reentrancy item as a Phase 0 verify. README and TODO updated to mat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
2026-06-13 feat: USB CDC config protocol + native configurator and flasher tools
    Firmware: add a newline-delimited JSON config protocol over USB CDC
    (as_config/config_protocol + config_json via cJSON) with get/set/info/save/
    defaults/reboot. The CDC channel in as_hid_usb now buffers lines and dispatches
    to a handler registered in main, replying via usb_hid_cdc_write. A config
    generation counter lets the sensing pipeline pick up edits live, so stick/mouse
    changes apply without a reboot.
    Host tools (tools/, Python): a shared serial-protocol + profile library, an
    end-user Tkinter configurator (axes, deadzone, curve, filter, mouse, button
    maps, macros) that reads/applies over USB, and a developer CLI flas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
    [as_flash.py, configurator.py]
2026-06-14 feat(models): add parametric Tetra II spherical flexure joint (OpenSCAD)
    Re-creation of Jelle Rommers' "Tetra 2" remote-centre spherical flexure
    joint (Thingiverse thing:4841850, CC-BY) as an editable OpenSCAD model
    rather than a mesh copy. Three thin triangular blades lie in planes that
    intersect at the remote pivot, so the central hub rotates about a point
    floating ~50 mm in front of the joint. A bearing-free compliant gimbal
    candidate for the ultra-low-force stick.
    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
    [tetra2.scad, tetra2.stl]
2026-06-14 feat(models): use author's original Tetra II STEP/STL instead of rebuild
    After reading the source paper (Rommers et al., Precision Engineering 71
    (2021) 130-140, CC-BY), the real Tetra II is three nested tetrahedron
    elements with trapezoidal, linearly-tapered blades. That is not faithfully
    reproducible in OpenSCAD, so the parametric approximation is dropped in
    favour of the author's authoritative CAD.
    - add Tetra2.STEP (editable B-rep) and Tetra2.STL (ready to print)
    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
    [Tetra2.STEP, tetra2.scad, tetra2.stl]
2026-06-26 docs: make Tetra II flexure the primary hardware path
    Promote the Tetra II spherical flexure from an experimental community
    part to the primary stick pivot, with the ball-in-PTFE-cup magnetic pod
    reframed as the documented alternative/fallback. Dual-Hall magnetic
    sensing is unchanged; the flexure replaces both the ball pivot and the
    magnetic centering (its blades self-center), and the threaded 1-8 gf
    force adjuster is dropped (stiffness is set by blade geometry, measured
    on the bench).
    - Relocate models/community/tetra2-flexure -> models/tetra2-flexure
    - Rewrite README, HARDWARE, DESIGN_V2, models/README around the flexure;
    add the preview renders to the README hero and the hardware docs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
    [Tetra2.STEP]
2026-06-26 docs: add community health files and contributor metadata
    Make the repo ready for community contributions:
    - SECURITY.md: private vulnerability reporting plus the drive/wheelchair
    propose-only safety scope
    - SUPPORT.md: a where-to-ask table mapping needs to the right issue
    template / Discussions
    - .github/FUNDING.yml: commented sponsor-button template
    - .github/CODEOWNERS: @owenpkent as default reviewer
    - README: firmware/models CI, license, status, PRs-welcome, and
    discussions badges
    - CONTRIBUTING: point the print-and-report task and 3D-model conventions
    at the primary Tetra II flexure (alternative pod noted)
2026-06-26 docs: pin CC BY 3.0 for the flexure and add the CERN-OHL-P text
    - LICENSE-CERN-OHL-P-2.0.txt: verbatim CERN Open Hardware Licence v2
    (Permissive) so the README's hardware-licence claim is backed by text
    (root LICENSE remains MIT for code; GitHub still detects MIT)
    - models/tetra2-flexure/LICENSE: standalone CC BY attribution for the
    third-party flexure, so the part is self-describing if redistributed
    - Pin the flexure licence as Creative Commons Attribution, CC BY 3.0
    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
2026-08-12 docs: add a first-pass one-page PRD
    Scoped to Stage A "Glide": problem, target users, goals/non-goals,
    requirements (reusing the R1-R10 numbering from DESIGN_V2), success
    metrics, risks, milestones, and open questions.

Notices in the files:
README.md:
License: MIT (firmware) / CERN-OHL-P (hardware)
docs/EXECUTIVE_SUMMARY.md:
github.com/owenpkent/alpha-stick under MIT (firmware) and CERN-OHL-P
